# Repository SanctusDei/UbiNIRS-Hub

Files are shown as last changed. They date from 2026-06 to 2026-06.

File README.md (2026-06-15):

# UbiNIRS-Hub

**A self-contained handheld NIR sensing platform — acquisition, preprocessing,
inference, and field adaptation run entirely on-device. No cloud, no tethering.**

Built on Raspberry Pi 3A+ with a TI DLP NIRScan Nano and 5-inch DSI touchscreen.
<br><sub>Jiahao Gong · Xurui Li · Weiwei Jiang</sub>

---

## Hardware

| Component | Notes |
|---|---|
| Spectrometer | TI DLP NIRScan Nano (900–1700 nm, USB HID) |
| Compute | Raspberry Pi 3A+ (BCM2837B0, ARM Cortex-A53) |
| Display | 5-inch DSI touchscreen (800×480) |
| Battery monitor | INA219 over I²C (addr 0x42) — optional |
| Enclosure | Custom 3D-printed housing (STL models in `stl/`) |
| Power | 2S LiPo (7.4 V nominal) — optional |

---

## Quick Start

### 1. Dependencies

```bash
sudo apt-get install libudev-dev libusb-1.0-0-dev
pip install numpy scipy pandas scikit-learn joblib
```

### 2. Compile the native library (Raspberry Pi only)

```bash
chmod +x rebuild_so.sh
./rebuild_so.sh
```

This regenerates the SWIG wrapper from `src/NIRScanner.i`, compiles the C++
sources under `src/`, and links the final `_NIRScanner.so`.

### 3. Launch

```bash
sudo python3 gui_app.py
```

> **Root required** — the NIRScan Nano uses USB HID. See
> [pyusb permissions](https://stackoverflow.com/questions/3738173).

### 4. Boot-time auto-start

```bash
chmod +x setup_autostart.sh
./setup_autostart.sh
```

Configures a systemd `.desktop` entry and passwordless sudo so the GUI
launches automatically on reboot.

---

## Project Structure

```
NIRScanner-Python/
├── gui_app.py             Main GUI (SpectrometerApp) — entry point
├── gui_scan.py            Scan workflow mixin (acquisition, graph, CSV save)
├── gui_ml.py              ML engine mixin (training, inference, memory)
├── gui_tasks.py           Task management mixin (CRUD, card-based browser)
├── NIRS.py                Python wrapper for _NIRScanner.so
├── INA219.py              INA219 battery coulomb counter
├── rebuild_so.sh          Recompile native library from C++ source
├── setup_autostart.sh     Deploy auto-start on boot
│
├── src/                   C++ source & SWIG interface
│   ├── NIRScanner.i       SWIG definition
│   ├── NIRScanner.cpp/h   Python–C++ bridge
│   ├── API.cpp/h          High-level scan API
│   ├── dlpspec_*.c/h      TI DLP Spectrum Library
│   ├── tpl.c/h            TivaWare Peripheral Library
│   ├── hid.c/hidapi.h     USB HID transport
│   ├── evm.cpp/h          EVM (evaluation module) driver
│   ├── usb.cpp/h          USB abstraction
│   ├── serial.c/h         Serial port helpers
│   └── CMakeLists.txt     Build configuration
│
├── stl/                  3D-printed enclosure models
│   ├── Base_Pedestal.STL
│   ├── Base_Back_Cover.STL
│   ├── Spectrometer_Container.STL
│   ├── Lens_Cover.STL
│   └── 3D_Printed_Experiment_Sheet.STL
│
├── models/                Trained model pickles
│
└── data/
    └── spectra/           spectrum CSVs
```

---

## Architecture

The GUI uses a **mixin-based** design on top of Tkinter:

```
┌──────────────────────────────────────────────┐
│              SpectrometerApp                  │
│  gui_app.py — window, hardware state,        │
│  battery heartbeat, page navigation          │
├──────────────────────────────────────────────┤
│  ScanWorkflowMixin      gui_scan.py          │
│  MLEngineMixin           gui_ml.py           │
│  TaskManagerMixin        gui_tasks.py         │
├──────────────────────────────────────────────┤
│  NIRS.py   ←  _NIRScanner.so  ←  C++ SWIG   │
│  INA219.py  (I²C battery sensor)             │
│  SQLite     (spectral_tasks.db)              │
└──────────────────────────────────────────────┘
```

### Key Design Decisions

| Concept | Implementation |
|---|---|
| **Hardware heartbeat** | Background poller thread; auto-disables UI on disconnect, restores on reconnect |
| **Scan generation counter** | Prevents stale scan callbacks from overwriting results after rapid re-scans |
| **Preprocessing pipeline** | SNV → Savitzky-Golay smoothing → derivative → StandardScaler (per-algorithm config) |
| **Stratified memory** | ≤100 samples; ≥3 per class; proportional pruning prevents catastrophic forgetting |
| **Hierarchical classifier** | Two-level HIGH/LOW split on raw absorbance mean; per-branch SVC/KNN/RF |
| **Dual-gate rejection** | Classifier confidence > θ ∧ PCA reconstruction error < τ → accept; else → `UNKNOWN` |
| **Dead-sensor detection** | Rejects scans with peak-to-peak intensity < 1e-6 |

---

## Features

### Spectral Scanning
- Hadamard & Column scan modes over configurable 900–1700 nm range
- Real-time intensity / absorbance / reflectance graph display
- PGA gain, lamp on/off, and hibernation control
- SNR diagnostic scans
- Auto-save as timestamped CSV (`data/spectra/`)

### On-Device Machine Learning
- **Classifiers**: SVM, Random Forest, KNN, LDA
- **Regressors**: SVR, PLS
- **Hierarchical classification** with per-branch confidence estimation
- **Dual-gate sample admission**: confidence threshold + PCA reconstruction-error gate
- **Stratified replay memory**: bounded buffer with class-balanced pruning
- **On-device field adaptation**: incremental retraining without cloud connectivity
- Leave-One-Out cross-validation

### Task Management
- SQLite-backed task CRUD with card-based touch browser
- Classification & regression task types with tag-based organization
- Model export/import (joblib `.pkl`)
- Batch prediction with majority voting

### System
- INA219 battery coulomb counter with capacity estimation
- System IP display with async refresh
- Automatic hardware reconnection on USB disconnect
- Fullscreen 800×480 DSI display with touch keyboard

---

## Usage

### Scanning
1. Open the **SCAN** page
2. Press the large **SCAN** button
3. Toggle **INT / ABS / REF** to switch graph modes
4. Scans auto-save to `data/spectra/`

### Training
1. In **TASKS** → **+ NEW**, choose Classification or Regression
2. Select an algorithm (SVM, RF, KNN, LDA, SVR, PLS)
3. Scan reference samples, assign labels in the training UI
4. Tap **TRAIN** — metrics display automatically
5. The model saves to `models/` and is ready for prediction

### Prediction
1. From the **TASKS** page, select a trained task
2. Switch to **PREDICT** mode
3. Scan an unknown sample — the result appears with confidence score
4. Low-confidence or out-of-distribution scans are rejected as `UNKNOWN` via the dual-gate mechanism

### Battery
When an INA219 sensor is connected, the status bar shows real-time voltage,
current, cumulative mAh consumed, and estimated remaining capacity.

---

## Citation

```bibtex
@inproceedings{gong2026ubinirshub,
  author    = {Gong, Jiahao and Li, Xurui and Jiang, Weiwei},
  title     = {UbiNIRS-Hub: A Mobile Near-Infrared Sensing Platform for
               On-Device Field Adaptation in Ubiquitous Material Analysis},
  year      = {2026},
}
```

---

## Related Repositories

- [NIRScanner-Imaging](https://github.com/HighTemplar-wjiang/NIRScanner-Imaging) — no-reference wavelength selection for NIR imaging
- [NIRScanner-Plotter](https://github.com/HighTemplar-wjiang/NIRScanner-Plotter) — Django server controlling NIRScan Nano + 2D plotter

---

## License

Includes source from the TI DLP NIRscan Nano GUI and DLP Spectrum Library.
Refer to the original distributions for their license terms.

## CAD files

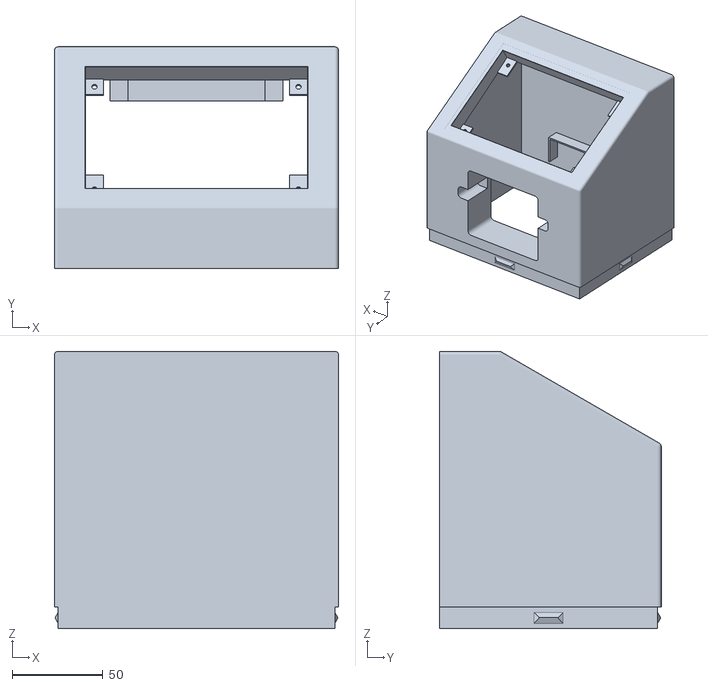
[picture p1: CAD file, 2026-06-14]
stl/Base_Pedestal.STL
156.4 x 122.0 x 152.8

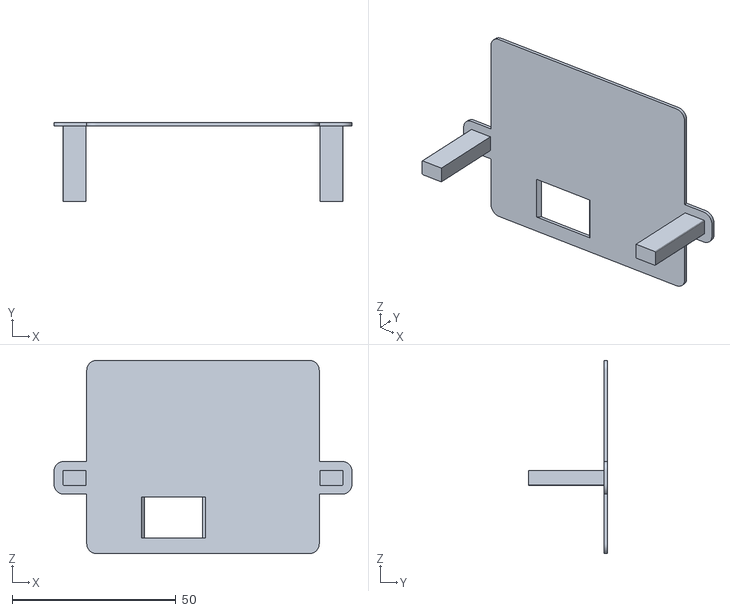
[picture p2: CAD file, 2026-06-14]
stl/Lens_Cover.STL
91.0 x 24.0 x 59.0

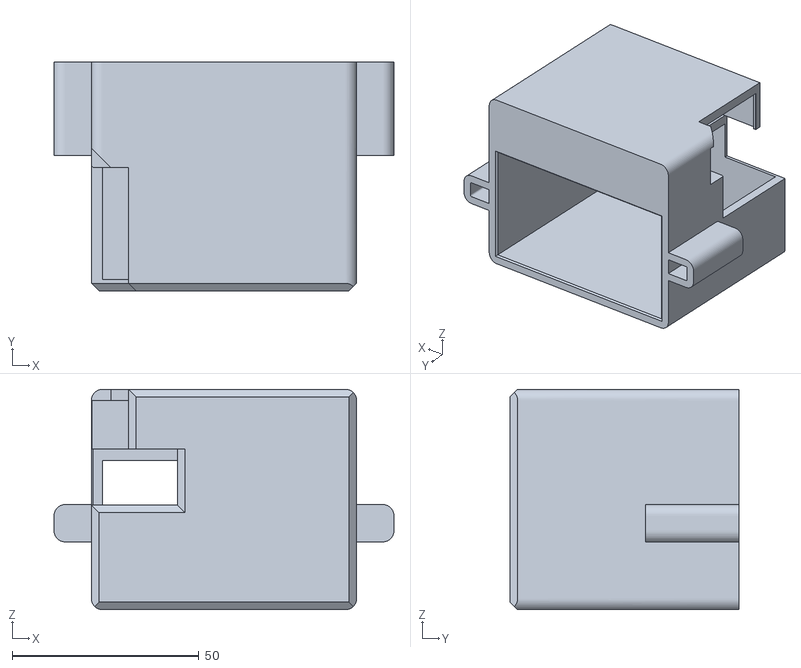
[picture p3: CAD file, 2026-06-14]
stl/Spectrometer_Container.STL
91.0 x 61.2 x 59.0

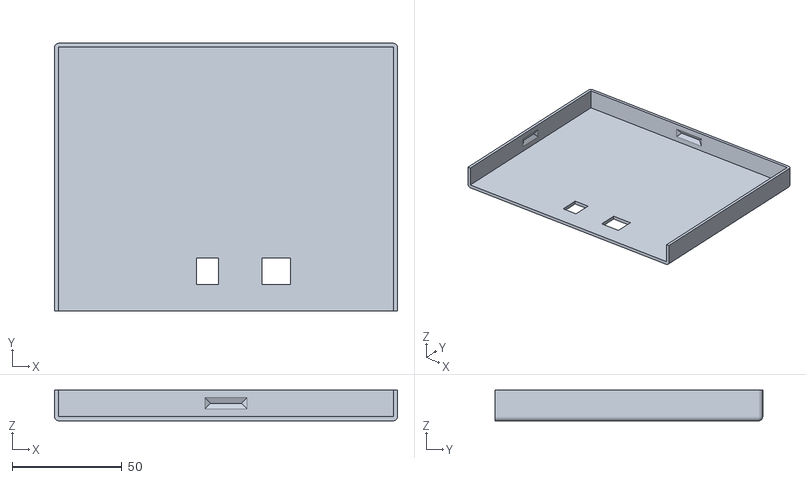
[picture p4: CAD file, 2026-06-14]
stl/Base_Back_Cover.STL
156.4 x 122.0 x 14.0

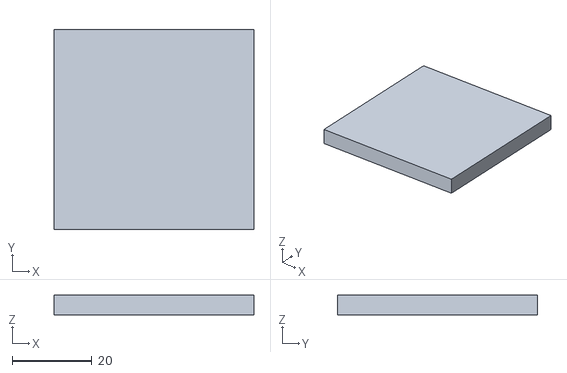
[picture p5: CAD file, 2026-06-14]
stl/3D_Printed_Experiment_Sheet.STL
50.0 x 50.0 x 5.00

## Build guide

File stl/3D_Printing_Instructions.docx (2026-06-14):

3D 外壳打印

元器件尺寸:

UPS HAT:

产品尺寸:56mm × 85mm

瞳孔直径:3.0mm

树莓派3A+

尺寸图:

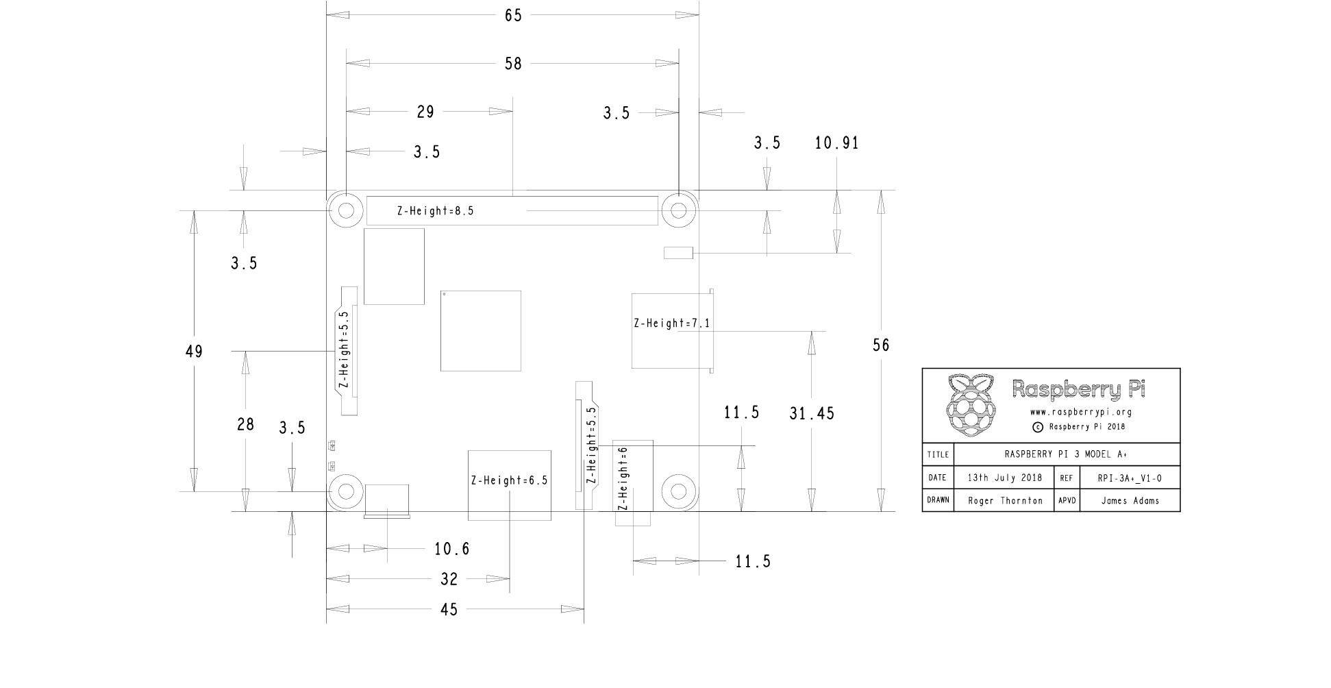
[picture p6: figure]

尺寸:65mm x 56mm

需要注意的元器件

1. 4个通孔的位置
2. USB口位置
3. 音频接口位置
4. HDMI接口位置
5. SD卡位置

USP Hat + 树莓派3A+

两者合体尺寸高度:42.05mm

5inch DSI LCD (B)

产品外形:129(-0.1~0.2)mm x 89mm

PCB尺寸:121mm x 76-77mm

DLP NIRScan nano

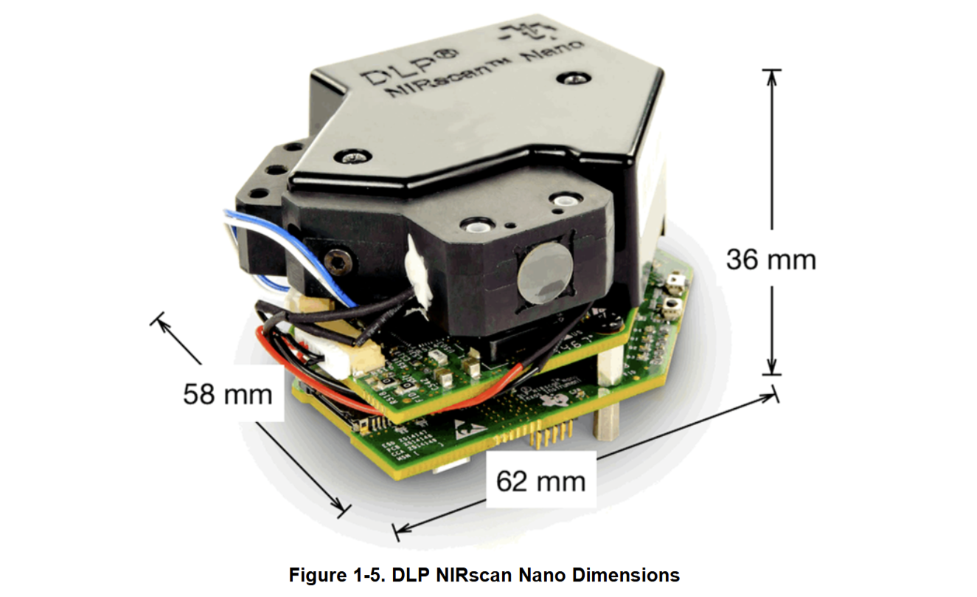
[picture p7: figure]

尺寸: 62mm x 58mm x 36mm

严格控制高度

外壳设计(待定):

底座:

150mm x 150mm

上平台

150mm x 100mm

高 120mm

外壳厚度

底部板子和充电容器:

长:85mm

宽59mm(56(pcb)+3(接口))

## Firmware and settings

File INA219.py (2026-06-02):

import smbus
import time

# Config Register (R/W)
_REG_CONFIG                 = 0x00
# SHUNT VOLTAGE REGISTER (R)
_REG_SHUNTVOLTAGE           = 0x01

# BUS VOLTAGE REGISTER (R)
_REG_BUSVOLTAGE             = 0x02

# POWER REGISTER (R)
_REG_POWER                  = 0x03

# CURRENT REGISTER (R)
_REG_CURRENT                = 0x04

# CALIBRATION REGISTER (R/W)
_REG_CALIBRATION            = 0x05

class BusVoltageRange:
    """Constants for ``bus_voltage_range``"""
    RANGE_16V               = 0x00      # set bus voltage range to 16V
    RANGE_32V               = 0x01      # set bus voltage range to 32V (default)

class Gain:
    """Constants for ``gain``"""
    DIV_1_40MV              = 0x00      # shunt prog. gain set to  1, 40 mV range
    DIV_2_80MV              = 0x01      # shunt prog. gain set to /2, 80 mV range
    DIV_4_160MV             = 0x02      # shunt prog. gain set to /4, 160 mV range
    DIV_8_320MV             = 0x03      # shunt prog. gain set to /8, 320 mV range

class ADCResolution:
    """Constants for ``bus_adc_resolution`` or ``shunt_adc_resolution``"""
    ADCRES_9BIT_1S          = 0x00      #  9bit,   1 sample,     84us
    ADCRES_10BIT_1S         = 0x01      # 10bit,   1 sample,    148us
    ADCRES_11BIT_1S         = 0x02      # 11 bit,  1 sample,    276us
    ADCRES_12BIT_1S         = 0x03      # 12 bit,  1 sample,    532us
    ADCRES_12BIT_2S         = 0x09      # 12 bit,  2 samples,  1.06ms
    ADCRES_12BIT_4S         = 0x0A      # 12 bit,  4 samples,  2.13ms
    ADCRES_12BIT_8S         = 0x0B      # 12bit,   8 samples,  4.26ms
    ADCRES_12BIT_16S        = 0x0C      # 12bit,  16 samples,  8.51ms
    ADCRES_12BIT_32S        = 0x0D      # 12bit,  32 samples, 17.02ms
    ADCRES_12BIT_64S        = 0x0E      # 12bit,  64 samples, 34.05ms
    ADCRES_12BIT_128S       = 0x0F      # 12bit, 128 samples, 68.10ms

class Mode:
    """Constants for ``mode``"""
    POWERDOW                = 0x00      # power down
    SVOLT_TRIGGERED         = 0x01      # shunt voltage triggered
    BVOLT_TRIGGERED         = 0x02      # bus voltage triggered
    SANDBVOLT_TRIGGERED     = 0x03      # shunt and bus voltage triggered
    ADCOFF                  = 0x04      # ADC off
    SVOLT_CONTINUOUS        = 0x05      # shunt voltage continuous
    BVOLT_CONTINUOUS        = 0x06      # bus voltage continuous
    SANDBVOLT_CONTINUOUS    = 0x07      # shunt and bus voltage continuous


class INA219:
    def __init__(self, i2c_bus=1, addr=0x42):
        self.bus = smbus.SMBus(i2c_bus);
        self.addr = addr

        # Set chip to known config values to start
        self._cal_value = 0
        self._current_lsb = 0
        self._power_lsb = 0
        #self.set_calibration_32V_2A()
        self.set_calibration_16V_5A()

    def read(self,address):
        data = self.bus.read_i2c_block_data(self.addr, address, 2)
        return ((data[0] * 256 ) + data[1])

    def write(self,address,data):
        temp = [0,0]
        temp[1] = data & 0xFF
        temp[0] =(data & 0xFF00) >> 8
        self.bus.write_i2c_block_data(self.addr,address,temp)

    def set_calibration_32V_2A(self):
        """Configures to INA219 to be able to measure up to 32V and 2A of current. Counter
           overflow occurs at 3.2A.
           ..note :: These calculations assume a 0.1 shunt ohm resistor is present
        """
        # By default we use a pretty huge range for the input voltage,
        # which probably isn't the most appropriate choice for system
        # that don't use a lot of power.  But all of the calculations
        # are shown below if you want to change the settings.  You will
        # also need to change any relevant register settings, such as
        # setting the VBUS_MAX to 16V instead of 32V, etc.

        # VBUS_MAX = 32V             (Assumes 32V, can also be set to 16V)
        # VSHUNT_MAX = 0.32          (Assumes Gain 8, 320mV, can also be 0.16, 0.08, 0.04)
        # RSHUNT = 0.1               (Resistor value in ohms)

        # 1. Determine max possible current
        # MaxPossible_I = VSHUNT_MAX / RSHUNT
        # MaxPossible_I = 3.2A

        # 2. Determine max expected current
        # MaxExpected_I = 2.0A

        # 3. Calculate possible range of LSBs (Min = 15-bit, Max = 12-bit)
        # MinimumLSB = MaxExpected_I/32767
        # MinimumLSB = 0.000061              (61uA per bit)
        # MaximumLSB = MaxExpected_I/4096
        # MaximumLSB = 0,000488              (488uA per bit)

        # 4. Choose an LSB between the min and max values
        #    (Preferrably a roundish number close to MinLSB)
        # CurrentLSB = 0.0001 (100uA per bit)
        self._current_lsb = .1  # Current LSB = 100uA per bit

        # 5. Compute the calibration register
        # Cal = trunc (0.04096 / (Current_LSB * RSHUNT))
        # Cal = 4096 (0x1000)

        self._cal_value = 4096

        # 6. Calculate the power LSB
        # PowerLSB = 20 * CurrentLSB
        # PowerLSB = 0.002 (2mW per bit)
        self._power_lsb = .002  # Power LSB = 2mW per bit

        # 7. Compute the maximum current and shunt voltage values before overflow
        #
        # Max_Current = Current_LSB * 32767
        # Max_Current = 3.2767A before overflow
        #
        # If Max_Current > Max_Possible_I then
        #    Max_Current_Before_Overflow = MaxPossible_I
        # Else
        #    Max_Current_Before_Overflow = Max_Current
        # End If
        #
        # Max_ShuntVoltage = Max_Current_Before_Overflow * RSHUNT
        # Max_ShuntVoltage = 0.32V
        #
        # If Max_ShuntVoltage >= VSHUNT_MAX
        #    Max_ShuntVoltage_Before_Overflow = VSHUNT_MAX
        # Else
        #    Max_ShuntVoltage_Before_Overflow = Max_ShuntVoltage
        # End If

        # 8. Compute the Maximum Power
        # MaximumPower = Max_Current_Before_Overflow * VBUS_MAX
        # MaximumPower = 3.2 * 32V
        # MaximumPower = 102.4W

        # Set Calibration register to 'Cal' calculated above
        self.write(_REG_CALIBRATION,self._cal_value)

        # Set Config register to take into account the settings above
        self.bus_voltage_range = BusVoltageRange.RANGE_32V
        self.gain = Gain.DIV_8_320MV
        self.bus_adc_resolution = ADCResolution.ADCRES_12BIT_32S
        self.shunt_adc_resolution = ADCResolution.ADCRES_12BIT_32S
        self.mode = Mode.SANDBVOLT_CONTINUOUS
        self.config = self.bus_voltage_range << 13 | \
                      self.gain << 11 | \
                      self.bus_adc_resolution << 7 | \
                      self.shunt_adc_resolution << 3 | \
                      self.mode
        self.write(_REG_CONFIG,self.config)

    def set_calibration_16V_5A(self):
        """Configures to INA219 to be able to measure up to 16V and 5A of current. Counter
           overflow occurs at 16A.
           ..note :: These calculations assume a 0.01 shunt ohm resistor is present
        """
        # By default we use a pretty huge range for the input voltage,
        # which probably isn't the most appropriate choice for system
        # that don't use a lot of power.  But all of the calculations
        # are shown below if you want to change the settings.  You will
        # also need to change any relevant register settings, such as
        # setting the VBUS_MAX to 16V instead of 32V, etc.

        # VBUS_MAX = 16V             (Assumes 16V, can also be set to 32V)
        # VSHUNT_MAX = 0.08          (Assumes Gain 2, 80mV, can also be 0.32, 0.16, 0.04)
        # RSHUNT = 0.01               (Resistor value in ohms)

        # 1. Determine max possible current
        # MaxPossible_I = VSHUNT_MAX / RSHUNT
        # MaxPossible_I = 8.0A

        # 2. Determine max expected current
        # MaxExpected_I = 5.0A

        # 3. Calculate possible range of LSBs (Min = 15-bit, Max = 12-bit)
        # MinimumLSB = MaxExpected_I/32767
        # MinimumLSB = 0.0001529              (61uA per bit)
        # MaximumLSB = MaxExpected_I/4096
        # MaximumLSB = 0,0012207              (488uA per bit)

        # 4. Choose an LSB between the min and max values
        #    (Preferrably a roundish number close to MinLSB)
        # CurrentLSB = 0.00016 (uA per bit)
        self._current_lsb = 0.1524  # Current LSB = 100uA per bit

        # 5. Compute the calibration register
        # Cal = trunc (0.04096 / (Current_LSB * RSHUNT))
        # Cal = 13434 (0x347a)

        self._cal_value = 26868

        # 6. Calculate the power LSB
        # PowerLSB = 20 * CurrentLSB
        # PowerLSB = 0.002 (2mW per bit)
        self._power_lsb = 0.003048  # Power LSB = 2mW per bit

        # 7. Compute the maximum current and shunt voltage values before overflow
        #
        # Max_Current = Current_LSB * 32767
        # Max_Current = 3.2767A before overflow
        #
        # If Max_Current > Max_Possible_I then
        #    Max_Current_Before_Overflow = MaxPossible_I
        # Else
        #    Max_Current_Before_Overflow = Max_Current
        # End If
        #
        # Max_ShuntVoltage = Max_Current_Before_Overflow * RSHUNT
        # Max_ShuntVoltage = 0.32V
        #
        # If Max_ShuntVoltage >= VSHUNT_MAX
        #    Max_ShuntVoltage_Before_Overflow = VSHUNT_MAX
        # Else
        #    Max_ShuntVoltage_Before_Overflow = Max_ShuntVoltage
        # End If

        # 8. Compute the Maximum Power
        # MaximumPower = Max_Current_Before_Overflow * VBUS_MAX
        # MaximumPower = 3.2 * 32V
        # MaximumPower = 102.4W

        # Set Calibration register to 'Cal' calculated above
        self.write(_REG_CALIBRATION,self._cal_value)

        # Set Config register to take into account the settings above
        self.bus_voltage_range = BusVoltageRange.RANGE_16V
        self.gain = Gain.DIV_2_80MV
        self.bus_adc_resolution = ADCResolution.ADCRES_12BIT_32S
        self.shunt_adc_resolution = ADCResolution.ADCRES_12BIT_32S
        self.mode = Mode.SANDBVOLT_CONTINUOUS
        self.config = self.bus_voltage_range << 13 | \
                      self.gain << 11 | \
                      self.bus_adc_resolution << 7 | \
                      self.shunt_adc_resolution << 3 | \
                      self.mode
        self.write(_REG_CONFIG,self.config)

    def getShuntVoltage_mV(self):
        self.write(_REG_CALIBRATION,self._cal_value)
        value = self.read(_REG_SHUNTVOLTAGE)
        if value > 32767:
            value -= 65535
        return value * 0.01

    def getBusVoltage_V(self):
        self.write(_REG_CALIBRATION,self._cal_value)
        self.read(_REG_BUSVOLTAGE)
        return (self.read(_REG_BUSVOLTAGE) >> 3) * 0.004

    def getCurrent_mA(self):
        value = self.read(_REG_CURRENT)
        if value > 32767:
            value -= 65535
        return value * self._current_lsb

    def getPower_W(self):
        self.write(_REG_CALIBRATION,self._cal_value)
        value = self.read(_REG_POWER)
        if value > 32767:
            value -= 65535
        return value * self._power_lsb
        
if __name__=='__main__':

    # Create an INA219 instance.
    ina219 = INA219(addr=0x42)
    while True:
        bus_voltage = ina219.getBusVoltage_V()             # voltage on V- (load side)
        shunt_voltage = ina219.getShuntVoltage_mV() / 1000 # voltage between V+ and V- across the shunt
        current = ina219.getCurrent_mA()                   # current in mA
        power = ina219.getPower_W()                        # power in W
        p = (bus_voltage - 6)/2.4*100
        if(p > 100):p = 100
        if(p < 0):p = 0

        # INA219 measure bus voltage on the load side. So PSU voltage = bus_voltage + shunt_voltage
        #print("PSU Voltage:   {:6.3f} V".format(bus_voltage + shunt_voltage))
        #print("Shunt Voltage: {:9.6f} V".format(shunt_voltage))
        print("Load Voltage:  {:6.3f} V".format(bus_voltage))
        print("Current:       {:9.6f} A".format(current/1000))
        print("Power:         {:6.3f} W".format(power))
        print("Percent:       {:3.1f}%".format(p))
        print("")

        time.sleep(2)

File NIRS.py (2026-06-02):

# NIRScanner Python Wrapper
# Created by Weiwei Jiang
#

import os, sys
sys.path.append(os.path.join(os.path.dirname(__file__), "./"))

import atexit
from _NIRScanner import *

import ctypes


class NIRS:

    class TYPES:
        COLUMN_TYPE = 0
        HADAMARD_TYPE = 1
        SLEW_TYPE = 2

    def __init__(self):
        self.nirs_obj = new_NIRScanner()
        atexit.register(self._cleanup)

    def _cleanup(self):
        print("Cleanning up NIRS instance.")
        delete_NIRScanner(self.nirs_obj)

    def scan_snr(self, scan_type="hadamard"):
        if scan_type == "hadamard":
            hadamard_flag = True
        elif scan_type == "column":
            hadamard_flag = False
        else:
            print("Unknow scan type {}.".format(scan_type))
        results_str = NIRScanner_scanSNR(self.nirs_obj, hadamard_flag)

        # Convert to Python object and return. 
        return eval(results_str)

    def scan(self, num_repeats=1):
        NIRScanner_scan(self.nirs_obj, False, num_repeats)

    @staticmethod
    def _safe_int(val, default=0):
        """Convert string to int, returning default on empty or invalid input."""
        try:
            return int(val)
        except (ValueError, TypeError):
            return default

    @staticmethod
    def _safe_float(val, default=0.0):
        """Convert string to float, returning default on empty or invalid input."""
        try:
            return float(val)
        except (ValueError, TypeError):
            return default

    def get_scan_results(self):
        results_dict = {}
        results_str = NIRScanner_getScanData(self.nirs_obj)
        results_str = results_str.split("\n")

        # Deserialization.
        for item in results_str:
            keyvalue = item.split(":")
            if len(keyvalue) == 2:
                results_dict[keyvalue[0]] = keyvalue[1]

        # Type conversion - all guarded against empty/malformed C++ output.
        if "valid_length" in results_dict:
            length = self._safe_int(results_dict.get("valid_length", "0"))
            results_dict["valid_length"] = length

            # Convert numerical results (filter empty strings from split).
            if "wavelength" in results_dict:
                results_dict["wavelength"] = [
                    self._safe_float(item) for item in results_dict["wavelength"].split(",")[:length]
                    if item.strip()
                ]
            if "intensity" in results_dict:
                results_dict["intensity"] = [
                    self._safe_int(item) for item in results_dict["intensity"].split(",")[:length]
                    if item.strip()
                ]
            if "reference" in results_dict:
                results_dict["reference"] = [
                    self._safe_int(item) for item in results_dict["reference"].split(",")[:length]
                    if item.strip()
                ]

        if "temperature_system" in results_dict:
            results_dict["temperature_system"] = self._safe_int(results_dict["temperature_system"]) / 100.0
        if "temperature_detector" in results_dict:
            results_dict["temperature_detector"] = self._safe_int(results_dict["temperature_detector"]) / 100.0
        if "humidity" in results_dict:
            results_dict["humidity"] = self._safe_int(results_dict["humidity"]) / 100.0
        if "pga" in results_dict:
            results_dict["pga"] = self._safe_int(results_dict["pga"])

        return results_dict

    def scan_collect(self, num_repeats=1, max_retries=1):
        """Scan and collect results with data validation.

        Returns (success: bool, results: dict).
        On failure, clears error status and retries up to max_retries times.
        """
        for attempt in range(max_retries + 1):
            self.scan(num_repeats)
            results = self.get_scan_results()

            intensities = results.get("intensity", [])
            wavelengths = results.get("wavelength", [])
            header = results.get("header_version", "0")

            # Validate: must have real data
            if intensities and wavelengths and len(intensities) > 0:
                # Check for garbage header version (valid headers < 0x100000)
                hv = self._safe_int(header, 0)
                if hv > 0x100000:
                    print(f"[NIRS] WARNING: Suspicious header version {hv} (0x{hv:X}), "
                          f"attempt {attempt+1}/{max_retries+1}")
                    if attempt < max_retries:
                        self.clear_error_status()
                        continue
                    # Last attempt - accept data despite bad header

                # Check for all-zero intensities: indicates _interpretData()
                # failed at the C++ level and mScanResults was zeroed (or
                # retained stale zeros). A real spectrum always has non-zero
                # intensity values.
                if all(v == 0 for v in intensities):
                    print(f"[NIRS] WARNING: All intensities are zero - "
                          f"interpretation likely failed "
                          f"(attempt {attempt+1}/{max_retries+1})")
                    if attempt < max_retries:
                        self.clear_error_status()
                        continue

                return True, results

            # No valid data
            print(f"[NIRS] WARNING: Scan returned no valid data "
                  f"(attempt {attempt+1}/{max_retries+1})")
            if attempt < max_retries:
                self.clear_error_status()

        return False, results

    def display_version(self):
        return NIRScanner_readVersion(self.nirs_obj)

    def set_hibernate(self, new_value: bool):
        return NIRScanner_setHibernate(self.nirs_obj, new_value)

    def set_config(self, scanConfigIndex=8, scan_type=1, num_patterns=228, num_repeats=6, 
                   wavelength_start_nm=900, wavelength_end_nm=1700, width_px=7):
        return NIRScanner_setConfig(self.nirs_obj, scanConfigIndex, scan_type, num_patterns, num_repeats, 
                                    wavelength_start_nm, wavelength_end_nm, width_px)
    
    def set_pga_gain(self, new_value):
        return NIRScanner_setPGAGain(self.nirs_obj, new_value)

    def set_lamp_on_off(self, new_value):
        return NIRScanner_setLampOnOff(self.nirs_obj, new_value)
    
    def clear_error_status(self):
        return NIRScanner_resetErrorStatus(self.nirs_obj)
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

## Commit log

2026-06-02 Cleanup: remove build artifacts, Sources/, and temporary files
    - Remove build artifacts: _NIRScanner.so, lib/, src/build/, src/cmake-build-debug/
    - Remove 111 Hadamard matrix .bin files (~30 MB, regenerated at build time)
    - Remove Sources/ (19 MB TI NIRScan Nano original Qt GUI reference)
    - Remove Jupyter checkpoints, IDE configs, old test files
    - Update .gitignore with comprehensive rules for build artifacts
    - Keep core: gui_*.py, src/ C++ source, data/, models/, dash/
    [task_1_dataset.csv, task_2_dataset.csv, task_4_dataset.csv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]
2026-06-02 Fix hierarchical classifier: HIGH branch always predicted low_labels[0]
    Root cause: _hierarchical_predict() assigned ALL HIGH-mean samples to
    low_labels[0] (first alphabetically-sorted low class), causing ABS, air,
    and half of PLA samples to all be misclassified as PETG.
    Changes:
    - _hierarchical_train(): add symmetric clf3 training for HIGH samples
    - _hierarchical_predict(): use clf3 for HIGH, proper UNKNOWN fallback
    - _train_model_worker(): store clf3 + high_labels in hierarchical_data
    - gui_scan.py: update is_hier check to accept clf3 as well as clf2
    - Backward compatible: missing clf3 key -> HIGH samples get UNKNOWN
    [gui_ml.py, gui_scan.py]
2026-06-04 Fix hierarchical classifier & add StandardScaler + dead sensor detection
    - _hierarchical_predict: now uses raw_means for level assignment
    (post-SNV mean is near-zero → random split). Accepts per-sample
    raw absorbance means so the HIGH/LOW split is meaningful.
    - Add _branch_confidence(): per-sample confidence from the branch
    classifier that actually made the prediction (SVC/RF/KNN).
    - _hierarchical_predict now returns (predictions, confidences) tuple.
    - Save StandardScaler preprocessor into model .pkl dict and apply it
    during inference for SVM/KNN/PCR/SVR/LDA pipelines.
    - Persist trimmed feature cache (X/y .npy) after stratified pruning.
    - Defer cache .npy write until user confirms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
    [gui_ml.py, gui_scan.py]
2026-06-04 Rewrite README.md with comprehensive project documentation
    - Project overview and hardware/software requirements
    - Detailed feature list (scanning, ML, task management, system)
    - Quick start guide with compilation and auto-start instructions
    - Full project structure tree
    - Architecture diagram with mixin-based design explanation
    - Usage guide for scanning, training, prediction, and battery monitoring
    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
2026-06-04 Update README: Raspberry Pi 4/5 → Raspberry Pi 3A+
2026-06-14 Align codebase with UbiComp/ISWC 2026 paper experimental logic
    - Add PCA reconstruction-error gate (Section 2.3.2): fit PCA on training data,
    compute per-sample reconstruction MSE, reject if error > learned threshold
    - Integrate dual-gate rejection: confidence threshold AND PCA error gate
    produce unified UNKNOWN abstention label (Section 2.3.2)
    - Reduce MAX_MEMORY_SAMPLES from 500 to 100 for bounded replay buffer (Section 2.3.1)
    - Update window title to UbiNIRS-Hub v2.0
    - Update README with paper citation, dual-gate features, architecture details
    [gui_app.py, gui_ml.py, gui_scan.py]
2026-06-14 Update spectral datasets with recent experimental scans
    Includes Cotton, Nylon, Polyester, Wool, ABS, PLA, and PETG spectra
    for textile and polymer classification experiments (Sections 3.2-3.3).
    [ABS1_Blue_Hadamard 1_468123_20260605_112459.csv, ABS1_Blue_Hadamard 1_468124_20260605_112502.csv, ABS1_Blue_Hadamard 1_468125_20260605_112505.csv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]
2026-06-14 Clean up unnecessary files from repository
    Remove intermediate ML data (dash/, test_/, data/task_3D_*), stale models
    (T.pkl/TK.pkl/TR.pkl), dev database (spectral_tasks.db), empty __init__.py,
    and SWIG auto-generated files (src/NIRScanner_wrap.cxx, NIRScanner.py, list.py).
    Add .gitignore rules: dash/, test_/, *.db, *.npy, *.jsonl, SWIG outputs.
    [task_10_dataset.csv, task_11_dataset.csv, task_12_dataset.csv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]
2026-06-14 Remove Paper section, tighten opening header
    Replace centered HTML header with clean markdown H1 + bold tagline.
    Drop the redundant Paper section (details already in Citation).
2026-06-14 Add 3D-printed enclosure STL models and update README
    - 5 STL files for custom handheld enclosure (Base, Back Cover,
    Spectrometer Container, Lens Cover, Experiment Sheet)
    - 3D printing instructions document
    - README: add stl/ to project structure and Enclosure to hardware table
    [3D_Printed_Experiment_Sheet.STL, Base_Back_Cover.STL, Base_Pedestal.STL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]
2026-06-14 Add adapted and expanded final models from Experiments B & C
    - 4 adapted models (Exp B Phase 3): trained on textile 4-layer + 1-layer
    fine-tune data — SVM, RF, KNN, LDA for 4-class distribution-shift adaptation
    - 4 expanded models (Exp C Phase 3): trained on PLA+ABS + added PETG
    class — SVM, RF, KNN, LDA for 3-class expansion
    - All verified against paper: drift/recovery within ±2pp, UDR/FAR 100%/0%
2026-06-15 Clean up README project structure: remove stale model filenames and specific CSV count
    Removed outdated model pickle entries from the directory tree since they no
    longer reflect the current models/ contents. Generalized the spectra description
    to avoid coupling to an exact file count.
